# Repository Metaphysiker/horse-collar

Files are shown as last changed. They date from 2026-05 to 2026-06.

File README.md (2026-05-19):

# Horse Collar Monitoring System

Detects horse activity (standing, lying, rolling) and sends alerts for potential colic or distress. Device mounts on a chest belt.

---

## Current Status (2026-05-19)

Hardware ordered from BerryBase, delivery expected 2026-05-19 to 2026-05-21. Nothing built yet.

### Key constraints
- User has **no soldering tools** — all connections must be solderless
- User has a **personal server** for data logging
- Single stable box with some outside space

### Next steps
1. Receive hardware from BerryBase
2. Order weatherproof enclosure from reichelt.de or conrad.ch
3. Order UWB modules from AliExpress (`Makerfabs ESP32 UWB DW1000` x3)
4. Order mini breadboard (~170 pin) to hold boards together
5. Wire up BNO085 to HUZZAH32 via Qwiic cable
6. Set up Arduino IDE and flash firmware
7. Log baseline data for 1 week before building alerts
8. Set up Twilio voice call alerts

---

## Hardware

### Ordered from BerryBase

| Item | Product Nr | Price |
|---|---|---|
| Adafruit BNO085 IMU Breakout | ADA4754 | - |
| Adafruit HUZZAH32 ESP32 Feather (with stacking headers) | ADA3619 | CHF 21.95 |
| LiPo Battery 3.7V 2500mAh JST | LP-785060-J | - |
| 40pin Jumper Female-Female | - | - |
| Soldered easyC/Qwiic to Dupont Female cable | SOL-333314 | - |

### Still needed
- Weatherproof enclosure ~80x65x40mm (IP65/67) — order from reichelt.de or conrad.ch
- UWB modules for height detection (order from AliExpress): `Makerfabs ESP32 UWB DW1000` x3

---

## Wiring

### BNO085 → HUZZAH32
Via Qwiic/STEMMA QT to female jumper wire cable (SOL-333314):

| BNO085 | HUZZAH32 |
|---|---|
| VCC | 3V |
| GND | GND |
| SDA | SDA |
| SCL | SCL |

### Battery → HUZZAH32
JST connector plugs directly into HUZZAH32 JST socket. Charge via Micro-USB into HUZZAH32.

---

## Enclosure

- Target size: ~80x65x40mm
- Must be IP65/67 (weatherproof — horse sweats, rain)
- Fix components inside with double-sided velcro + polyethylene foam padding
- Use small cable tie on Qwiic cable to prevent connector strain
- Use mini breadboard (~170 pin) to hold HUZZAH32 and BNO085 together as one unit

---

## Detection Logic

### Sampling rate
- Read BNO085 every **1 second**
- Send data to server only on **state change** + heartbeat every **5 minutes**

### States
| State | Condition |
|---|---|
| Standing | Stable orientation, pitch/roll ~0° |
| Lying down | Pitch or roll > 60° for more than 10 seconds |
| Moving | Activity detected, upright orientation |
| Rolling (colic risk) | Activity detected + tilted orientation |

### BNO085 data to use
- **Gravity vector** — changes clearly when horse lies down
- **Absolute orientation / rotation vector** — pitch and roll angles
- **Activity classification** — stable, moving etc.
- **Linear acceleration** — sudden movements

### Battery monitoring
Read battery voltage via pin A13 on HUZZAH32:

| Voltage | Charge |
|---|---|
| 4.2V | 100% |
| 3.9V | ~60% |
| 3.7V | ~30% |
| 3.4V | ~5% |

---

## Data Logging (Server)

Log everything first to establish baseline — learn what normal looks like for this specific horse before building alerts.

### Payload (every state change)
```json
{
  "timestamp": "2026-05-19T08:00:00",
  "pitch": 12.3,
  "roll": 2.1,
  "activity": "stable",
  "acceleration": 0.12,
  "battery_voltage": 3.9,
  "battery_percent": 60,
  "state": "standing"
}
```

---

## Alerts (Twilio)

Voice call to mobile when abnormal state detected.

| Destination | Cost |
|---|---|
| Swiss mobile | ~$0.05 per call |
| Swiss landline | ~$0.01 per call |
| Twilio number | $1.15/month |

Trigger alert when:
- Horse rolling for more than 30 seconds (colic risk)
- Horse lying down for unusually long time
- Battery below 20%

---

## Future: UWB Height Detection

3x `Makerfabs ESP32 UWB DW1000` modules (~€60 total from AliExpress):
- Anchor 1: high (stable roof edge) — covers indoor + outdoor
- Anchor 2: low (stable wall, ground level)
- Tag: horse collar

Detects absolute height → confirms lying down independently of IMU orientation.
Combined with BNO085 gives much richer picture (lying + rolling = strong colic indicator).

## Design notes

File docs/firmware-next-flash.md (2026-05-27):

# Planned Firmware Changes (next flash)

## 1. Send quaternion instead of Euler angles

Currently, the firmware converts the BNO085 rotation vector to pitch/roll on-device and discards the quaternion. This causes:
- Gimbal lock (pitch flips to ±127° when roll exceeds 90°)
- Loss of yaw entirely
- Server-side horse roll approximation is inaccurate at high angles

**Change:** Send `qw`, `qx`, `qy`, `qz` raw. Keep pitch/roll alongside for backward compatibility during transition.

```cpp
doc["qw"] = curQw;
doc["qx"] = curQx;
doc["qy"] = curQy;
doc["qz"] = curQz;
```

Server and frontend then compute pitch, roll, yaw, and horse roll from quaternion — no gimbal lock, correct at all angles.

---

## 2. Send Unix timestamp as integer

Currently, `isoFromUnix()` converts `time_t` to an ISO string in firmware. This is unnecessary and error-prone (TZ confusion).

**Change:** Send the raw Unix timestamp directly.

```cpp
// instead of:
obj["timestamp"] = isoFromUnix(r.unixTime);
// send:
obj["timestamp"] = r.unixTime;
```

Server parses with `DateTimeOffset.FromUnixTimeSeconds(v).UtcDateTime`. No conversion, no formatting, always UTC.

---

## 3. Add yaw (compass heading)

`SH2_ROTATION_VECTOR` already uses the magnetometer and is already enabled — yaw costs zero extra sensor reads, just one extra `atan2` computation.

**Change:** Extract yaw from the existing quaternion read.

```cpp
float yaw = atan2(2*(curQw*curQz + curQx*curQy), 1 - 2*(curQy*curQy + curQz*curQz)) * 180.0f / PI;
```

Send as `yaw` field. Useful for detecting which direction the horse is facing and long-term movement patterns.

---

## 4. Re-sync NTP on every WiFi connection

The ESP32 HUZZAH32 has no external 32.768 kHz crystal — it uses an internal 150 kHz RC oscillator which is temperature-sensitive and drifts significantly (~10 min per 36 h observed). NTP is the only source of accurate time.

Currently `timeSynced` is `RTC_DATA_ATTR` — NTP syncs once at hard boot and never again.

Since WiFi is already connected for every batch upload, re-syncing NTP costs almost nothing (one UDP packet). Just remove the `timeSynced` guard so `syncTime()` is called every upload cycle.

**Change:** Remove `RTC_DATA_ATTR bool timeSynced` and always call `syncTime()` when WiFi is up.

---

## 5. Fix timezone offset

`TZ_OFFSET = 3600` (UTC+1, CET) is wrong in summer — Switzerland is CEST (UTC+2 = 7200). Since timestamps use `gmtime()` this is harmless for stored data, but fix for correctness and any local-time logging.

**Change in `config.*.h`:**
```cpp
// Option A: hardcode CEST
#define TZ_OFFSET 7200

// Option B: use POSIX timezone string (handles DST automatically)
configTime(0, 0, NTP_SERVER);
setenv("TZ", "CET-1CEST,M3.5.0,M10.5.0/3", 1);
tzset();
```

Option B is correct year-round.

---

## 6. Additional sensor data (low impact)

These use already-enabled reports or fast additional reads:

| Field | Source | Cost |
|---|---|---|
| `linearAccelX/Y/Z` | `SH2_LINEAR_ACCELERATION` (already enabled) | free — just send components instead of magnitude |
| `gyroX/Y/Z` | `SH2_GYROSCOPE_CALIBRATED` (already enabled) | free — just send components instead of magnitude |
| `gravityX/Y/Z` | `SH2_GRAVITY` | one extra report enable + poll |
| `temperature` | `SH2_TEMPERATURE` | one extra report enable + poll |

Sending raw X/Y/Z components instead of magnitudes gives the server more information to work with (direction of movement, not just intensity).

---

## Summary of JSON payload change

**Current:**
```json
{
  "timestamp": "2026-05-26T17:44:52",
  "pitch": -8.3, "roll": -7.7,
  "acceleration": 0.11, "angularVelocity": 0.03,
  "temperature": 25.0, "state": "Standing", "alertReason": null
}
```

**After:**
```json
{
  "timestamp": 1748283892,
  "qw": 0.997, "qx": -0.042, "qy": -0.031, "qz": 0.012,
  "pitch": -8.3, "roll": -7.7, "yaw": 142.5,
  "acceleration": 0.11, "angularVelocity": 0.03,
  "linearAccelX": 0.08, "linearAccelY": -0.07, "linearAccelZ": 0.03,
  "gyroX": 0.01, "gyroY": -0.02, "gyroZ": 0.01,
  "temperature": 25.0, "state": "Standing", "alertReason": null
}
```

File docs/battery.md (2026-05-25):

# Battery Life Estimates

## Hardware

- **Board:** Adafruit HUZZAH32 (ESP32)
- **Sensor:** BNO085 (~1.1 mA active)
- **Battery:** 2500 mAh LiPo
- **Charger:** built into HUZZAH32, charges at ~200 mA via USB-C

---

## Power consumption

| Mode | Current draw |
|---|---|
| ESP32 deep sleep | ~0.01 mA |
| ESP32 active, WiFi off (sensor read) | ~80 mA |
| ESP32 active, WiFi transmitting | ~180 mA |

---

## Current setup — deep sleep with batch sending

The firmware deep sleeps between readings and only connects to WiFi every `sendEveryN` cycles to upload a batch. WiFi connect + send + disconnect takes ~15 seconds.

**Assumptions:**
- Sensor read per wake: ~500 ms at 80 mA
- WiFi per batch: ~15 s at 180 mA
- `sendEveryN = 60`

| Sleep interval | Upload every | Avg current | Est. battery life (2500 mAh) |
|---|---|---|---|
| 1s | ~60s | ~68 mA | **~37 hours** |
| 2s | ~2 min | ~38 mA | **~66 hours (~2.7 days)** |
| 5s | ~5 min | ~16 mA | **~6.5 days** |
| 10s | ~10 min | ~8 mA | **~13 days** |

---

## Trade-offs

- **1s** — maximum data density, good for active monitoring or data collection sessions
- **2s** — good balance for daily use, ~2.5 days between charges
- **5s** — field deployment, weekly charging
- **10s** — long-term unattended monitoring, charge every ~2 weeks

Alert states always send immediately regardless of interval — battery impact is minimal since alerts are rare.

---

## Notes

- Real-world battery capacity is typically 80–90% of rated value — reduce estimates accordingly.
- WiFi connection time varies by signal strength. Poor signal = longer connect time = faster drain.
- The HUZZAH32 battery percentage reading is approximate (±5–10%).

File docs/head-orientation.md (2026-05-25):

# Head Orientation — How It Works

## The sensor

The BNO085 chip measures orientation relative to gravity. It knows which way is "down" at all times. It reports three values:

- **Pitch (sensor)** — tilt on one axis
- **Roll (sensor)** — tilt on the other axis
- **Yaw (sensor)** — rotation around the vertical axis (like a compass heading)

## The problem: we don't know how the chip sits in the casing

The chip is glued inside a plastic casing in some unknown rotation. This means we don't know which sensor axis maps to which head movement. What the sensor calls "pitch" might actually be the head tilting sideways, or forward, depending on how the chip is mounted.

## What the horse's head can do

- **Pitch (horse)** — nose pointing up or down (like nodding yes)
- **Roll (horse)** — head tilting sideways, ear toward shoulder (like tilting an airplane wing)
- **Yaw (horse)** — head turning left or right (like saying no) — this is compass direction

## What we actually care about for lying down detection

When a horse lies down on its side, the head **rolls (horse)** heavily to one side — the ear goes toward the ground. This is a large, sustained change in orientation.

The problem: we don't know if roll (horse) shows up as pitch (sensor), roll (sensor), or a mix of both, because we don't know the chip orientation.

## How to figure it out

Look at the sensor data during a confirmed lying-down period. One or both of pitch (sensor) / roll (sensor) will show a large, sustained value that is clearly different from when the horse is standing. That's your roll (horse) signal.

## Tilt — a shortcut that avoids the chip orientation problem

Tilt is calculated as:

```
tilt = sqrt(pitch² + roll²)
```

This is Pythagoras applied to angles. It measures the total deviation from level, regardless of which direction. It doesn't matter how the chip is rotated in the casing — tilt will always be large when the head is far from level.

- Horse standing normally: tilt ≈ 17–28° (head slightly forward and down is normal)
- Horse lying on its side: tilt expected to be much larger (60–90°+)

Tilt doesn't tell you which direction the head tilted, just how far. But for detecting lying down, that's enough.

## What the overnight data will tell us

By leaving the collar on overnight and looking at the data:

1. **If the horse lies down** — we'll see a long period of low acceleration (still) with high tilt. We can measure the exact tilt range for lying down and use it as a threshold.

2. **If the horse never lies down** — we still have a solid baseline for "normal upright active head." Any sustained reading outside that range is unusual and worth flagging.

## Bonus: compass direction

Yaw (sensor) tells you which direction the horse's nose is pointing — north, east, west, etc. Not useful for health monitoring, but interesting.

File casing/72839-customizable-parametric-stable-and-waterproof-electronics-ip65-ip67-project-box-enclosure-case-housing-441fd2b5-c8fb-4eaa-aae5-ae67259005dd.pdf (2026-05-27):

## Customizable parametric stable

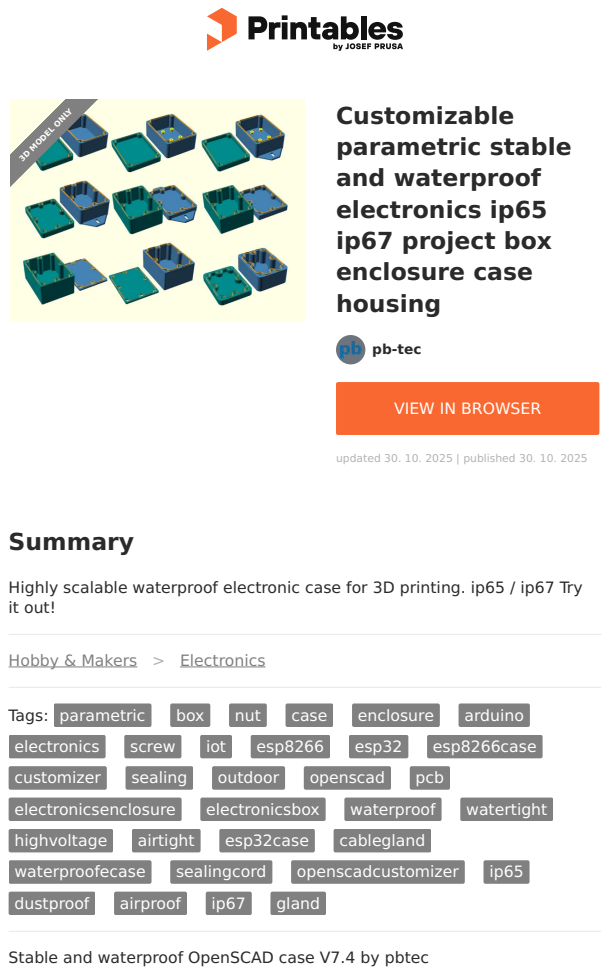
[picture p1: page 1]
Summary; Tags:; parametric; box; nut; case; enclosure; arduino; electronics; screw; iot; esp8266; esp32; esp8266case; customizer; sealing; outdoor; openscad; pcb; electronicsenclosure; electronicsbox; waterproof; watertight; highvoltage; airtight; esp32case; cablegland; waterproofecase; sealingcord; openscadcustomizer; dustproof; airproof; gland; pb-tec; and waterproof electronics ip65 ip67 project box enclosure case housing; updated 30. 10. 2025 | published 30. 10. 2025; 3D MODEL ONLY

VIEW IN BROWSER (https://printables.com/model/72839-customizable-parametric-stable-and-waterproof-elec)

Highly scalable waterproof electronic case for 3D printing. ip65 / ip67 Try
it out!

Hobby & Makers (https://printables.com/model?categoryId=48) > Electronics (https://printables.com/model?categoryId=52)

Stable and waterproof OpenSCAD case V7.4 by pbtec

See here a wonderful comment from a user:
“This is INSANE! You sir deserve deserve the biggest applaud out there. This is a box to rule them all! ... I have to admit I first didn't understand what you meant with SCAD possibilities, and resized it on my own by cutting xD then I checked out SCAD version and my jaw simply dropped to the ground! ... This is a GREAT project!”

Highly scalable electronic case for 3D printing. Try it out!
You’ll need to download the free, opensource OpenSCAD software from https://openscad.org/ and install it. Once installed, open the ".scad" file in Openscad. Activate Customizer under View/Customizer and have fun experimenting!

Fixed version 7.4
It seems that special characters in the code have again led to the code not working properly for some. I apologize for this. I have now created a new version 7.4 where this is fixed. I would be very interested to know if everything works as expected for you now. Thanks for your feedback in the comments

Enhancements in Version 7.2:

Hot melt copper nut support
Screw hole options: Can be configured to pass through the entire case, with the option to position the nut at the bottom of the case Flexible mounting options: 1 to 3 holes on all sides for cable glands or switches
Improved PCB support: Now compatible with up to 3 different PCBs holders instead of just one
Base bottom mounting holes added (not recommended if the housing should be highly waterproof)
Gasket can now be printed (TPU).
Expanded screw support: In addition to countersunk screws, round, flat, and hex head screws are now supported

I would love to hear whether you like the new version!

No support needed to print

You don't know Openscad? No problem. Customize the case in Openscad and then export the stl file from Openscad (F6 then F7). Then Import the stl file into your best known 3d program to make holes for example. You can also make the holes afterwards with the drilling machine ;-)

Additional Screws (M2,M2.5,M3,M4 or M5), the matching nuts (hex or square) needed.
If you want to protect your electronics from humidity also “silicone sealing cord” is needed. Available at AliExpress or ebay.

•
•

•

•

•

•
•

For waterproof cases you can use silicone sealing cord with diameters from 1 to 3mm
To use also without sealing cord. The groove and ridge gives the housing a high stability and tightness.
Use of regular nuts or square nuts
Define outer vertical radius of corners
Echo output in console shows inner and outer size and more
Echo output shows the needed length of the screws
Use screws from m2 up to m5
Default are 4 screws at each corner. For large cases add addtional ones in the middle of both x and y sides if needed
Use several predefined wall mount holder, some with multiple mounting holes (up to 3)

Important!
If you use standard or square nuts, you need to pause the printer a certain level to insert the nuts
If you need a stable and waterproof case please print with 100% infill I'm aware that sometimes, when using too big or too small parameters, there are some rendering issues. To prevent such issues change only one parameter at once and check the result.

I never tested the water proofness of this case. For more information see https://blog.prusaprinters.org/watertight-3d-printing-part-2_53638/

pbtec / pb-tec.ch
https://www.instagram.com/pbtecch/

For Projects with ESP32, ESP8266, Arduino, Raspberry, Sonoff, Shelly, IoBroker, IoT. In- and outdoor :-)

Let me see your prints, and remakes and pls don't forget to like this print

use https://paypal.me/pbtec if you want to spend me a cold beer. Thanks in advance :-)

If you want to support my project, please use the links below to start your shopping. No additional charges for you, but I get a commission of your purchases

Brass hot melting insert nuts (starter) sets: https://s.click.aliexpress.com/e/_DezuAlHhttps://s.click.aliexpress.com/e/_DeWsPMp

Or individual sizes:
https://s.click.aliexpress.com/e/_DkaQObjhttps://s.click.aliexpress.com/e/_DCrO22p

## Model files

I also recommend using special hot iron to insert the nuts in the right angle:
https://s.click.aliexpress.com/e/_DcHd8Ep

round silicone sealing cord foam white
Aliexpress: https://s.click.aliexpress.com/e/_AdVXC6
Ebay: https://www.ebay.com/itm/184394411044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 (https://www.ebay.com/itm/184394411044?siteid=0&campid=5338823684&customid=&toolid=10001)

round silicone sealing cord foam black
Aliexpress: https://s.click.aliexpress.com/e/_A32aUQ
Ebay: https://www.ebay.com/itm/353309685702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 (https://www.ebay.com/itm/353309685702?siteid=0&campid=5338823684&customid=&toolid=10001)

round silicone sealing solid cord white
Aliexpress: https://s.click.aliexpress.com/e/_A07nM2
Ebay: https://www.ebay.com/itm/133527877200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 (https://www.ebay.com/itm/133527877200?siteid=0&campid=5338823684&customid=&toolid=10001)

Some tags to better find this project:
Electrical Junction, Distribution box, Connection box, Cable Branch box,
Electronic, Housing, ip67, DIY, Project Box, Instrument Case, Wiring socket
box, Sealed, Cable gland, Shell, weatherproof, outdoor, airtight, watertight, dustproof, electronics, pcb, airproof, enclosure, parametric

sample2-ultimatewaterproofcase_v6.stl

sample1-ultimatewaterproofcase_v6.stl

ultimatewaterproofcase_v61.scad

ultimatewaterproofcase_v74.scad

## License

This work is licensed under a
Creative Commons (4.0 International License)

Attribution—Noncommercial—Share Alike (http://creativecommons.org/licenses/by-nc-sa/4.0/)

✖ | Sharing without ATTRIBUTION
✔ | Remix Culture allowed
✖ | Commercial Use
✖ | Free Cultural Works
✖ | Meets Open Definition

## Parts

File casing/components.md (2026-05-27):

# Component Dimensions

## LiPo Battery
- **Part:** PKCell LP-785060-J
- **EAN:** 4251266702207
- **Size:** 7.8 × 50 × 60 mm
- **Voltage:** 3.7V DC (single cell)
- **Weight:** 54g gross

## Adafruit HUZZAH32 (ESP32 Feather)
- **Part:** Adafruit #3619
- **EAN:** 4060137061714
- **Size:** 22.9 × 57.1 mm (verify height with components)
- **Weight:** 10g gross
- **Origin:** USA
- **MCU:** ESP32 dual core 240 MHz Tensilica LX6
- **RAM:** 520 KB SRAM
- **Flash:** 4 MB (on WROOM32 module)
- **WiFi:** 802.11b/g/n, integrated PCB antenna
- **Bluetooth:** Classic + BLE
- **RTC:** ESP32 supports external 32 kHz crystal, but HUZZAH32 does not populate it — uses internal RC oscillator (~150 kHz, drifts significantly)
- Includes USB interface, LiPo JST connector, reset button
- LiPo battery and USB cable not included

## BNO085 IMU Breakout
- **Part:** Adafruit #4754
- **EAN:** 4060137066818
- **Size:** 25.6 × 22.7 × 4.6 mm
- **Weight:** 2.5g
- **Origin:** USA
- Connected via I2C (4 wires)

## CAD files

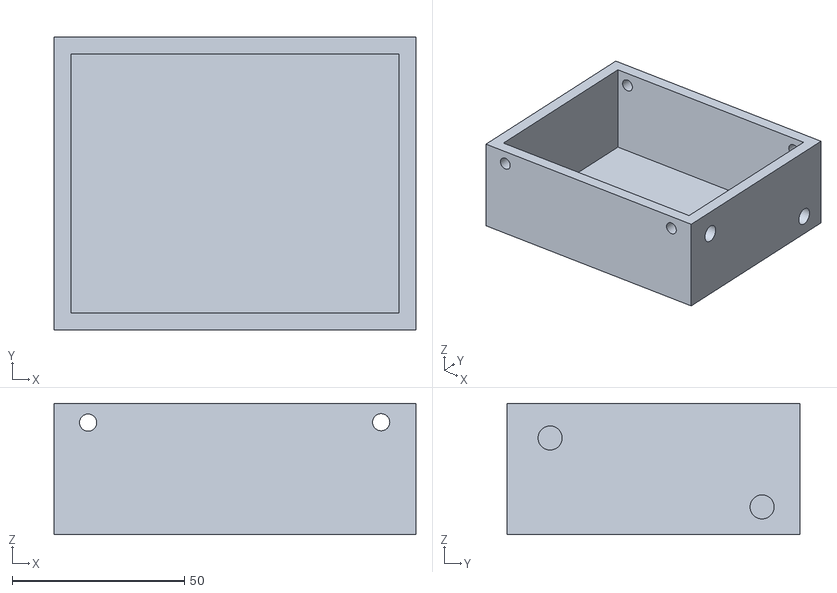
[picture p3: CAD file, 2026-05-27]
casing/MainBody.stl
105.0 x 85.0 x 38.0

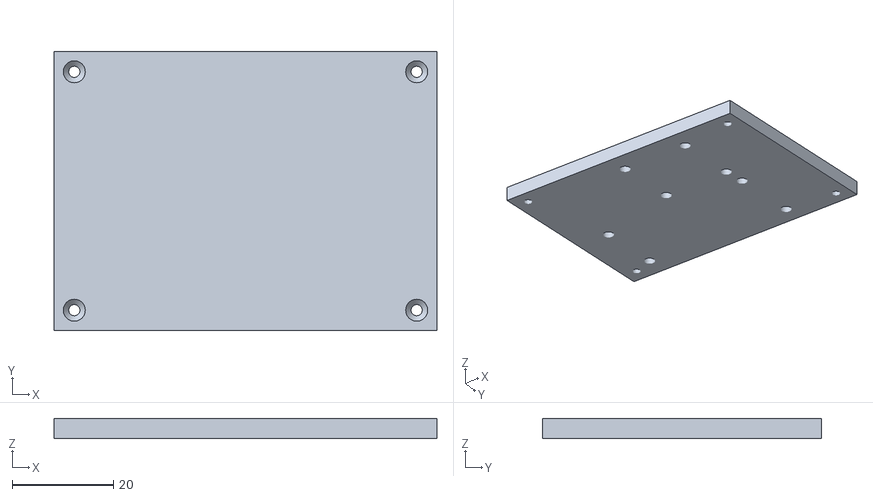
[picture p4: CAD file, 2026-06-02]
casing/20260519-horse-collar-with-heat-inserts/horse-collar-with-heat-inserts-lid.stl
75.5 x 55.0 x 4.00

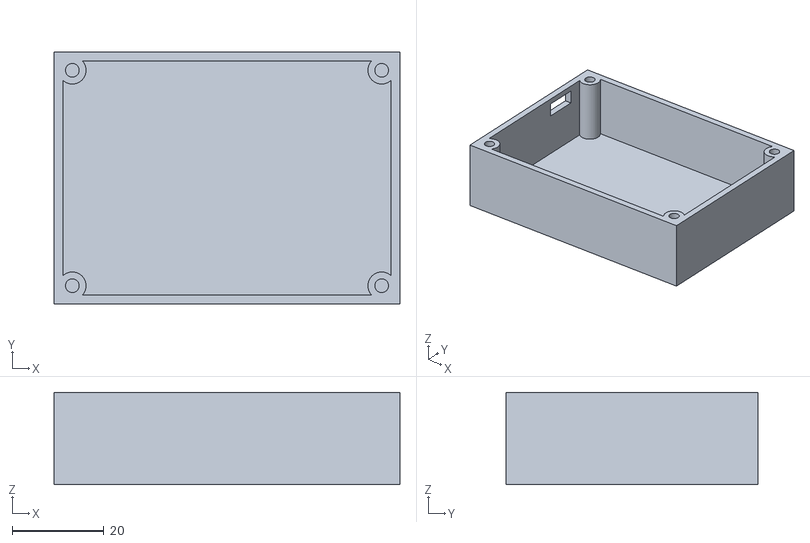
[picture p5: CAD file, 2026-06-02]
casing/20260519-horse-collar-with-heat-inserts/horse-collar-with-heat-inserts-box.stl
75.5 x 55.0 x 20.1

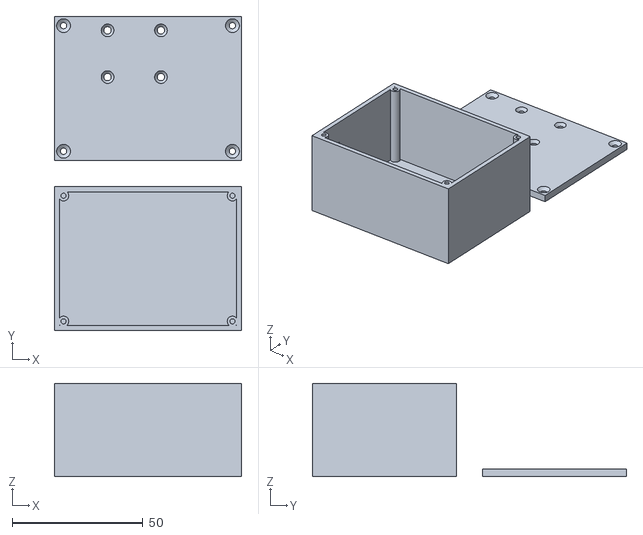
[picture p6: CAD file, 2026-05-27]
casing/sandro-box.stl
71.5 x 120.0 x 35.7

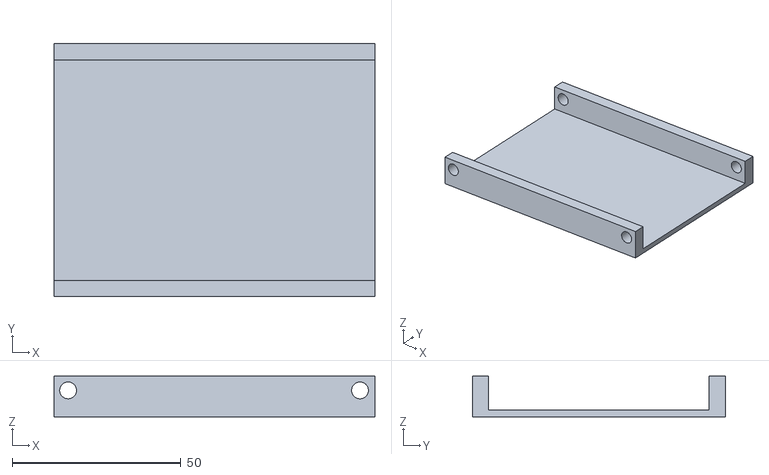
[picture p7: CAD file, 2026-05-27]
casing/Lid.stl
95.0 x 75.0 x 12.0

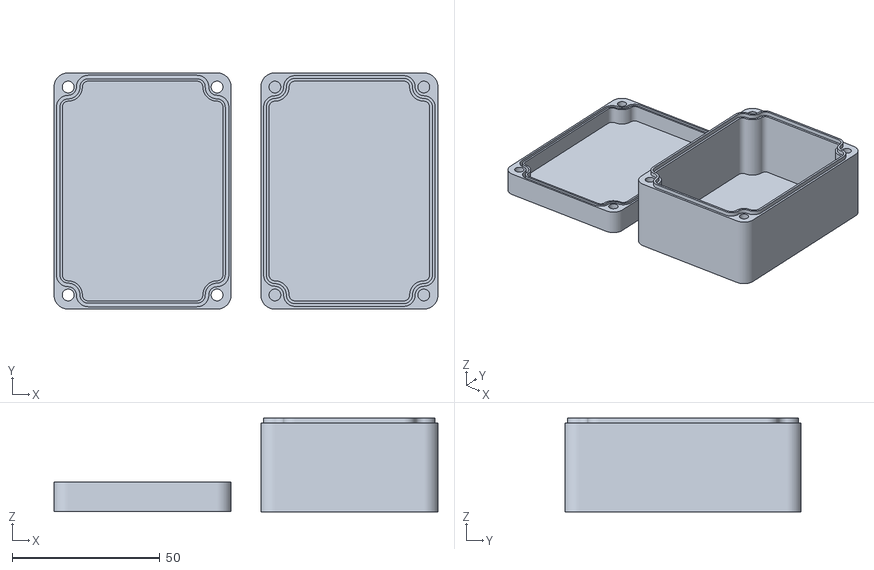
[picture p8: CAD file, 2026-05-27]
casing/Sample1-UltimateWaterproofCase_V6.stl
130.0 x 80.0 x 31.7

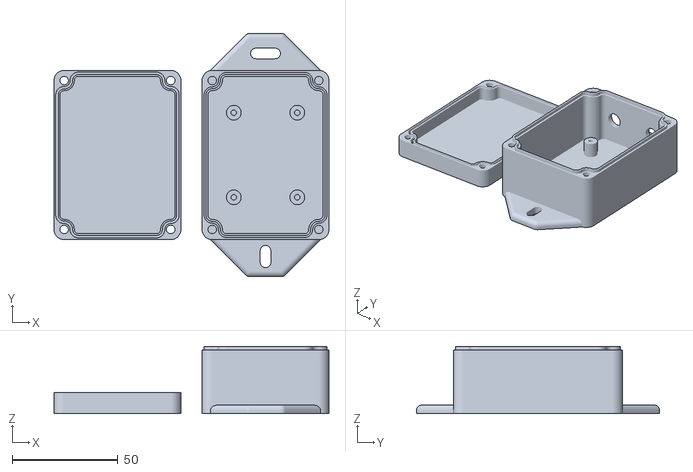
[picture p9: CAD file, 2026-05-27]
casing/sample2-ultimatewaterproofcase_v6.stl
130.0 x 115.0 x 31.7

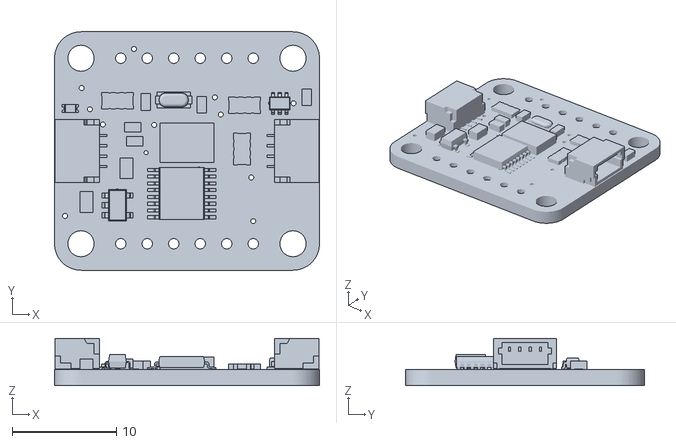
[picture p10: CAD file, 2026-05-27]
casing/4754 BNO085 STEMMA QT.stl
25.4 x 22.9 x 4.53

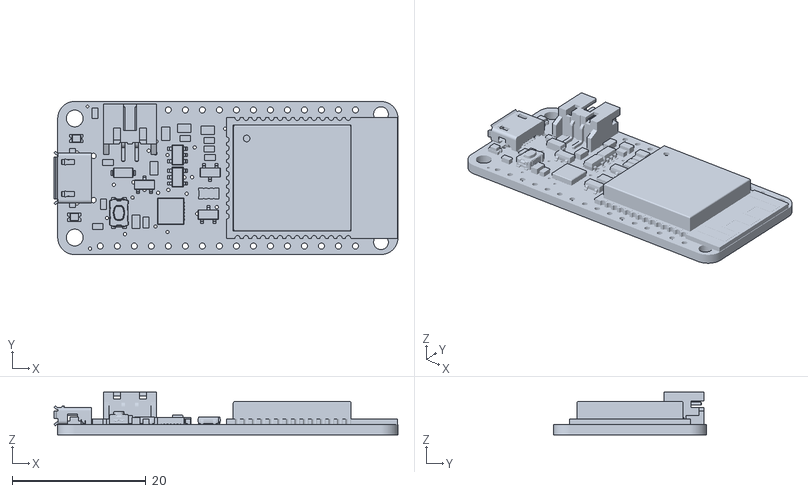
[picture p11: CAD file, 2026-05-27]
casing/3405 Adafruit HUZZAH32 ESP32 Feather.stl
51.4 x 22.9 x 6.37

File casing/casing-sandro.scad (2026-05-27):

module lid(){

    LID_SKIN = 2.5;   // top plate thickness (critical rigidity parameter)

    difference(){

        // ── Solid lid blank (structural cap) ───────────────
        rbox(OUT_L, OUT_W, LID_H);

        // ── Main internal clearance (BUT not full height) ──
        // Leaves a solid top skin
        translate([wall, wall, LID_SKIN])
            cube([
                IN_L,
                IN_W,
                LID_H - LID_SKIN + 1
            ]);

        // ── HUZZAH32 pocket (only where needed) ────────────
        translate([wall + HUZ_OFF_L,
                   wall + HUZ_OFF_W,
                   LID_SKIN])
            cube([
                HUZ_L + tol,
                HUZ_CAV_H,
                HUZ_W + tol
            ]);

        // ── BNO085 pocket ──────────────────────────────────
        translate([wall + BNO_OFF_L,
                   wall + BNO_OFF_W,
                   LID_SKIN])
            cube([
                BNO_L + tol,
                BNO_W + tol,
                BNO_H + tol
            ]);

        // ── Alignment post holes ───────────────────────────
        for (x=[10, OUT_L-10], y=[10, OUT_W-10])
            translate([x,y,-1])
                cylinder(d=post_fit, h=LID_SKIN + 20);

        // ── Screw clearance holes ──────────────────────────
        for (x=[10, OUT_L-10], y=[10, OUT_W-10])
            translate([x,y,-1])
                cylinder(d=screw_d, h=LID_H + 2);

        // ── USB-C cutout ───────────────────────────────────
        translate([OUT_L - wall - 0.1,
                   wall + HUZ_OFF_W + 8,
                   LID_SKIN + 2])
            cube([wall + 0.2, 10, 5]);

        // ── LED window ──────────────────────────────────────
        translate([wall + HUZ_OFF_L + 5,
                   OUT_W - wall - 0.1,
                   LID_SKIN + 2])
            cube([6, wall + 0.2, 3]);
    }
}

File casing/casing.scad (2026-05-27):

// ── Horse Collar Sensor Casing ───────────────────────────────────────
//
// Components:
//   Battery  PKCell LP-785060-J   7.8 × 50 × 60 mm  (lying flat, bottom layer)
//   HUZZAH32 Adafruit #3619      22.9 × 57.1 mm PCB (middle layer, centred)
//   BNO085   Adafruit #4754      25.6 × 22.7 × 4.6 mm (top layer, one end)
//
// Two-part print: bottom shell (battery) + lid (HUZZAH32 + BNO085)
// Joined by snap rim: rim on bottom shell slots into groove in lid.

// ── Tuneables ────────────────────────────────────────────────────────
show_shell      = true;   // show the printed shells
show_components = true;   // show battery / HUZZAH32 / BNO085

wall  = 2.0;   // shell wall / floor / ceiling thickness
tol   = 0.5;   // clearance added to each component cavity
cr    = 3.0;   // outer corner radius
$fn   = 40;

// Corner screws joining lid to bottom shell (M2.5, 4 corners)
screw_clr_d   = 2.7;   // M2.5 clearance hole through lid
screw_head_d  = 5.0;   // M2.5 pan head recess diameter
screw_head_h  = 1.8;   // pan head recess depth
screw_pilot_d = 2.0;   // M2.5 pilot hole in bottom shell (self-tapping)
screw_pilot_h = 8.0;   // pilot hole depth

// HUZZAH32 PCB locating pegs (press-fit into Adafruit Feather mounting holes)
pcb_peg_d      = 2.0;   // peg diameter — tight in 2.2 mm Feather holes; sand if needed
pcb_peg_h      = 3.5;   // peg height
HUZ_HOLE_IN_L  = 3.2;   // hole inset from short edge  (Adafruit Feather standard)
HUZ_HOLE_IN_W  = 1.7;   // hole inset from long edge

// BNO085 boss posts (M2.0 self-tapping screws inserted from inside case, up through PCB hole)
bno_boss_d     = 4.0;   // outer boss diameter
bno_screw_d    = 1.6;   // pilot hole diameter for M2 self-tapping
bno_pilot_dep  = 8.0;   // pilot hole depth into boss

// ── Component dimensions ─────────────────────────────────────────────
BAT_L = 60.0;   BAT_W = 50.0;   BAT_H = 7.8;

HUZ_L = 57.1;   HUZ_W = 22.9;
HUZ_PCB_H  = 1.6;    // PCB thickness
HUZ_COMP_H = 9.0;    // tallest SMD component above PCB (USB-C port)
HUZ_PIN_H  = 12.0;   // male pin tail below PCB — measured from female jumper cable (~12 mm)
HUZ_FEM_H  = 12.0;   // female Dupont socket height above PCB — measured jumper cable
HDR_W      = 2.54;   // header strip width (one row of 2.54mm pitch)
HUZ_H = HUZ_PCB_H + max(HUZ_COMP_H, HUZ_PIN_H);

BNO_L = 25.4;   BNO_W = 22.86;  BNO_H = 4.53;  // measured from STL bounding box

// ── Layout ───────────────────────────────────────────────────────────
// HUZZAH32 and BNO085 sit side-by-side in the width direction, centred together.
// Combined width: 22.9 + 2mm gap + 22.86 = 47.76mm — fits in 50mm inner width.

IN_L = BAT_L;                          // inner length = 60 mm
IN_W = BAT_W;                          // inner width  = 50 mm

OUT_L = IN_L + 2 * wall;
OUT_W = IN_W + 2 * wall;

BOT_H = wall + BAT_H + wall;           // bottom shell total height
LID_H = wall + HUZ_W + wall;           // lid total height — HUZZAH32 stands upright, height = HUZ_W

BNO_GAP   = 2.0;
BOARDS_W  = HUZ_W + BNO_GAP + BNO_W;

HUZ_OFF_L = (IN_L - HUZ_L) / 2;
HUZ_OFF_W = (IN_W - BOARDS_W) / 2;

BNO_OFF_L = (IN_L - BNO_L) / 2;
BNO_OFF_W = IN_W - BNO_W;

// HUZZAH32 mounting hole positions relative to PCB corner
huz_holes = [
  [HUZ_HOLE_IN_L,         HUZ_HOLE_IN_W        ],
  [HUZ_L - HUZ_HOLE_IN_L, HUZ_HOLE_IN_W        ],
  [HUZ_HOLE_IN_L,         HUZ_W - HUZ_HOLE_IN_W],
  [HUZ_L - HUZ_HOLE_IN_L, HUZ_W - HUZ_HOLE_IN_W],
];

// BNO085 mounting hole positions relative to board corner (from Adafruit Eagle PCB file)
bno_holes = [
  [ 2.54,  2.54],
  [22.86,  2.54],
  [ 2.54, 20.32],
  [22.86, 20.32],
];

// USB-C cutout
USB_W = 9.5;
USB_H = 4.0;
usb_y = wall + HUZ_OFF_W + HUZ_W / 2 - USB_W / 2;
usb_z = wall + HUZ_PCB_H;

// ── Component models ─────────────────────────────────────────────────
module huzzah32() {
    // STL (offset corrected — model origin is at x=−0.56)
    color("ForestGreen", 0.8) translate([0.56, 0, 0])
        import("3405 Adafruit HUZZAH32 ESP32 Feather.stl");
    // PCB slab
    color("ForestGreen", 0.4) cube([HUZ_L, HUZ_W, HUZ_PCB_H]);
    // Female headers — both long sides, above PCB
    color("Gold", 0.5) translate([0, 0, HUZ_PCB_H])
        cube([HUZ_L, HDR_W, HUZ_FEM_H]);
    color("Gold", 0.5) translate([0, HUZ_W - HDR_W, HUZ_PCB_H])
        cube([HUZ_L, HDR_W, HUZ_FEM_H]);
    // Male pins — both long sides, below PCB (sticking out from belly)
    color("CornflowerBlue", 0.8) translate([0, 0, -HUZ_PIN_H])
        cube([HUZ_L, HDR_W, HUZ_PIN_H]);
    color("CornflowerBlue", 0.8) translate([0, HUZ_W - HDR_W, -HUZ_PIN_H])
        cube([HUZ_L, HDR_W, HUZ_PIN_H]);
}

// ── Primitives ───────────────────────────────────────────────────────
module rbox(l, w, h) {
    hull()
        for (x = [cr, l - cr], y = [cr, w - cr])
            translate([x, y, 0]) cylinder(r = cr, h = h);
}

// Rectangular frame (solid outer minus hollow inner)
module rim_frame(l, w, h, t) {
    difference() {
        cube([l, w, h]);
        translate([t, t, -0.1])
            cube([l - 2*t, w - 2*t, h + 0.2]);
    }
}

// ── Bottom shell ─────────────────────────────────────────────────────
module bottom() {
    difference() {
        rbox(OUT_L, OUT_W, BOT_H);

        // Battery cavity (open top)
        translate([wall, wall, wall])
            cube([BAT_L + tol, BAT_W + tol, BOT_H]);

        // Groove clearance so rim doesn't hit the lid groove shoulder
        // (nothing to subtract here — open top handles it)
    }

    // Snap rim — rises from battery tray walls, slots into lid groove
    translate([wall, wall, BOT_H])
        rim_frame(IN_L, IN_W, snap_rim_h, snap_rim_t);
}

// ── Lid ──────────────────────────────────────────────────────────────
module lid() {
    difference() {
        union() {
            rbox(OUT_L, OUT_W, LID_H);

            // HUZZAH32 PCB locating pegs — hang from lid ceiling
            for (h = huz_holes)
                translate([wall + HUZ_OFF_L + h[0], wall + HUZ_OFF_W + h[1], LID_H - wall - pcb_peg_h])
                    cylinder(d = pcb_peg_d, h = pcb_peg_h);

            // BNO085 boss posts — hang from ceiling; PCB rests against boss tip, screw from inside
            for (h = bno_holes)
                translate([wall + BNO_OFF_L + h[0], wall + BNO_OFF_W + h[1], BNO_H + tol])
                    cylinder(d = bno_boss_d, h = LID_H - wall - BNO_H - tol);
        }

        // HUZZAH32 cavity (open bottom) — upright: depth=HUZ_W, Y-width=full header stack
        translate([wall + HUZ_OFF_L, wall + HUZ_OFF_W, -1])
            cube([HUZ_L + tol, HUZ_PIN_H + HUZ_PCB_H + HUZ_FEM_H + tol, HUZ_W + tol + 1]);

        // BNO085 cavity (open bottom)
        translate([wall + BNO_OFF_L, wall + BNO_OFF_W, -1])
            cube([BNO_L + tol, BNO_W + tol, BNO_H + tol + 1]);

        // Snap groove — frame-shaped recess at open bottom, accepts bottom shell rim
        translate([wall - snap_tol, wall - snap_tol, -1])
            rim_frame(
                IN_L + 2*snap_tol,
                IN_W + 2*snap_tol,
                snap_rim_h + 1,
                snap_rim_t + snap_tol
            );

        // USB-C cutout on right short face
        translate([OUT_L - wall - 0.1, usb_y, usb_z])
            cube([wall + 0.2, USB_W, USB_H]);

        // LED window on long face
        translate([wall + HUZ_OFF_L + 3, OUT_W - wall - 0.1, usb_z])
            cube([5, wall + 0.2, 3]);

        // BNO085 pilot holes — blind, from boss bottom upward (M2 screws from inside case)
        for (h = bno_holes)
            translate([wall + BNO_OFF_L + h[0], wall + BNO_OFF_W + h[1], BNO_H + tol - 0.1])
                cylinder(d = bno_screw_d, h = bno_pilot_dep + 0.1);
    }
}

// ── Dimensions ───────────────────────────────────────────────────────
echo(str("Outer footprint: ", OUT_L, " × ", OUT_W, " mm"));
echo(str("Bottom shell height: ", BOT_H, " mm"));
echo(str("Lid height:          ", LID_H, " mm"));
echo(str("Total assembled:     ", OUT_L, " × ", OUT_W, " × ", BOT_H + LID_H, " mm"));

// ── Render ───────────────────────────────────────────────────────────
if (show_shell) {
    % bottom();
    % translate([0, 0, BOT_H + 5]) lid();
}

if (show_components) {
    color("OrangeRed",    0.5) translate([wall, wall, wall])
        cube([BAT_L, BAT_W, BAT_H]);
    translate([wall + HUZ_OFF_L, wall + HUZ_OFF_W + HUZ_PCB_H + HUZ_FEM_H, wall + BAT_H + 1])
        rotate([90, 0, 0]) huzzah32();
    color("#1a1a1a") translate([wall + BNO_OFF_L, wall + BNO_OFF_W, BOT_H + 5 + wall + BNO_H])
        mirror([0, 0, 1])
            import("4754 BNO085 STEMMA QT.stl");
    // BNO085 boss posts — shown in component view for layout checking
    color("SteelBlue", 0.8)
        for (h = bno_holes)
            translate([wall + BNO_OFF_L + h[0], wall + BNO_OFF_W + h[1], BOT_H + 5 + wall + BNO_H + tol])
                cylinder(d = bno_boss_d, h = LID_H - wall - BNO_H - tol);
}

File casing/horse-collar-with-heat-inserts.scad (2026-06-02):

// ── Horse Collar Sensor Casing (heat-set insert version) ───────────────
// Components: LiPo Battery + HUZZAH32 (no headers) + BNO085
// Two-part print: box (battery) + flat lid (boards screwed in), joined by 4 corner M2 screws
// HUZZAH32 and BNO085 screwed face-down to lid via M2 heat-set inserts in boss posts

// ── Tuneables ──────────────────────────────────────────────────────────
// "box" = export box STL  |  "lid" = export lid STL  |  "preview" = both side by side  |  "assembled" = alignment check
part = "lid";
lid_assembled = (part == "assembled");
wall        = 2.0;   // wall and floor thickness
lid_depth   = 4.0;   // lid thickness — 4 mm minimum for M2 heat-set inserts
gap         = 3;   // clearance between battery top and board components
boards_gap  = 2.0;   // gap between HUZZAH32 and BNO085 in width direction
$fn         = 40;

// ── Component dimensions ───────────────────────────────────────────────
bat_length = 60.5;   bat_width = 50.0;   bat_depth = 7.8;

huz_length     = 51.0;    // official Adafruit + STL confirmed
huz_width      = 22.86;   // STL measured
huz_pcb_depth  = 1.6;     // PCB thickness
huz_comp_depth = 5.7;     // official total 7.3mm - PCB 1.6mm
huz_depth      = huz_pcb_depth + huz_comp_depth;

bno_length = 25.4;   bno_width = 22.86;   bno_depth = 4.53;

// USB-C cutout
usb_w = 9.5;
usb_h = 4.0;

// ── Mounting holes ─────────────────────────────────────────────────────
// BNO085 (from Adafruit Eagle PCB — 2.54 mm inset from each edge)
bno_holes  = [[2.54, 2.54], [22.86, 2.54], [2.54, 20.32], [22.86, 20.32]];
bno_hole_d = 2.2;   // M2 clearance

// HUZZAH32 mounting holes
// Eagle PCB positions + 0.56 mm STL X origin offset (STL starts at x=-0.56, corrected in huzzah32())
huz_stl_x = 0.56;
huz_holes = [
    [2.54  + huz_stl_x,  2.54],
    [48.26 + huz_stl_x,  1.84],
    [2.54  + huz_stl_x, 20.32],
    [48.26 + huz_stl_x, 20.96],
];
huz_hole_d = 2.2;   // M2 clearance

// ── Corner screw posts (M2) ───────────────────────────────────────────
post_od     = 6.0;   // outer diameter — sized for M2 heat-set insert
csink_d     = 4.5;
csink_depth = 1.4;
screw_clr_d = 2.2;   // M2 clearance through lid

// ── Corner heat-set inserts (M2) ──────────────────────────────────────
// M2 insert: 3.0 mm hole, 3.0 mm long — same spec as board inserts
// Use M2 × 8 mm screws
corner_ins_depth  = 3.0;
corner_ins_hole_d = 3.0;

// ── Board heat-set inserts (M2) ────────────────────────────────────────
// M2 insert: 3.2 mm OD, 3.0 mm long — boss hangs from lid interior
ins_depth  = 3.0;   // M2 insert length
ins_hole_d = 3.0;   // hole diameter (slightly under insert OD for press fit)

// ── Box dimensions ─────────────────────────────────────────────────────
bat_clear_x   = 0.5;   // clearance between battery and post inner edge (x, each side)
bat_clear_x_y = 0.5;   // clearance between battery and wall (y, each side)
// Length: battery + two end zones derived from post position (wall + post_od - 1 = screw_off + post_od/2)
box_length = bat_length + (wall + post_od - 1 + bat_clear_x) * 2;
box_width  = bat_width  + wall * 2 + bat_clear_x_y * 2;
// Depth: floor + battery + gap + boards hanging from lid
box_depth  = wall + bat_depth + gap + huz_depth;

inner_length = box_length - 2 * wall;
inner_width  = box_width  - 2 * wall;
inner_depth  = box_depth  - wall;

post_depth = box_depth - wall;
screw_off  = wall + post_od / 2 - 1;  // 1 mm into wall — insert hole still clears outer face

// ── Board layout (assembly / box coordinates) ──────────────────────────
// HUZZAH32: USB-C end flush with right wall; both boards centred in width
boards_total_width = huz_width + boards_gap + bno_width;
boards_start_y = wall + (inner_width - boards_total_width) / 2;

huz_off_x = 7;    // USB-C channel 9 mm deep
bno_off_y = boards_start_y;                                // BNO at low Y side
huz_off_y = boards_start_y + bno_width + boards_gap;       // HUZZAH at high Y side
bno_off_x = huz_off_x + huz_length - bno_length;           // BNO right-aligned under HUZZAH, away from JST port

// USB-C cutout position on right wall
usb_y = huz_off_y + huz_width / 2 - usb_w / 2;
usb_z = box_depth - huz_pcb_depth - usb_h;

// ── Modules ────────────────────────────────────────────────────────────

module box_body() {
    difference() {
        cube([box_length, box_width, box_depth]);
        // Hollow inside
        translate([wall, wall, wall])
            cube([inner_length, inner_width, inner_depth + 0.1]);
        // USB-C channel: cuts through left wall and into interior to reach port
        translate([-0.1, usb_y, usb_z])
            cube([huz_off_x + wall + 0.2, usb_w, usb_h]);
    }
}

module corner_post(x, y) {
    difference() {
        translate([x, y, wall])
            cylinder(h = post_depth, d = post_od);
        translate([x, y, wall + post_depth - corner_ins_depth])
            cylinder(h = corner_ins_depth + 0.1, d = corner_ins_hole_d);
    }
}

module corner_screw_hole() {
    cylinder(h = lid_depth + 0.2, d = screw_clr_d);
    cylinder(h = csink_depth, d1 = csink_d, d2 = screw_clr_d);
}

module lid() {
    difference() {
        cube([box_length, box_width, lid_depth]);
        // Corner screws
        translate([screw_off,              screw_off,            -0.1]) corner_screw_hole();
        translate([box_length - screw_off, screw_off,            -0.1]) corner_screw_hole();
        translate([screw_off,              box_width - screw_off,-0.1]) corner_screw_hole();
        translate([box_length - screw_off, box_width - screw_off,-0.1]) corner_screw_hole();
        // Heat-set insert holes — blind holes from interior face (z=lid_depth) going inward
        // PCB sits against interior face; screw enters from below through PCB hole into insert
        for (h = huz_holes)
            translate([huz_off_x + h[0], huz_off_y + h[1], lid_depth - ins_depth])
                cylinder(h = ins_depth + 0.1, d = ins_hole_d, $fn = 32);
        for (h = bno_holes)
            translate([bno_off_x + h[0], bno_off_y + h[1], lid_depth - ins_depth])
                cylinder(h = ins_depth + 0.1, d = ins_hole_d, $fn = 32);
    }
}

module huzzah32() {
    // STL origin is at x=-0.56 — shift so PCB left edge = x=0
    color("ForestGreen", 0.15) translate([0.56, 0, 0])
        import("3405 Adafruit HUZZAH32 ESP32 Feather.stl");
}

// Both boards face down from lid: PCB at z=box_depth, components hang into box
module place_huzzah() {
    translate([huz_off_x, huz_off_y + huz_width, box_depth])
        rotate([180, 0, 0])
            huzzah32();
}

module place_bno() {
    translate([bno_off_x, bno_off_y + bno_width, box_depth])
        rotate([180, 0, 0])
            import("4754 BNO085 STEMMA QT.stl");
}

module place_battery() {
    color("SkyBlue")
        translate([wall + post_od - 1 + bat_clear_x, wall + bat_clear_x_y, wall])
            cube([bat_length, bat_width, bat_depth]);
}

// ── Assembly ───────────────────────────────────────────────────────────
module box_assembly() {
    box_body();
    corner_post(screw_off,              screw_off);
    corner_post(box_length - screw_off, screw_off);
    corner_post(screw_off,              box_width - screw_off);
    corner_post(box_length - screw_off, box_width - screw_off);
}

module lid_print() {
    translate([0, 0, lid_depth])
        mirror([0, 0, 1])
            lid();
}

if (part == "box") {
    box_assembly();
} else if (part == "lid") {
    lid_print();
} else if (part == "preview") {
    box_assembly();
    translate([0, box_width + 10, 0]) lid_print();
    % place_huzzah();
    % color("DarkGrey", 0.15) place_bno();
    % place_battery();
} else if (part == "assembled") {
    % box_assembly();
    % translate([0, 0, box_depth + lid_depth]) mirror([0, 0, 1]) lid();
    place_huzzah();
    color("DarkGrey") place_bno();
    place_battery();
    color("Red")  for (h = huz_holes)
        translate([huz_off_x + h[0], huz_off_y + h[1], box_depth - 0.5])
            cylinder(h = 2, d = 1.5, $fn = 16);
    color("Blue") for (h = bno_holes)
        translate([bno_off_x + h[0], bno_off_y + h[1], box_depth - 0.5])
            cylinder(h = 2, d = 1.5, $fn = 16);
}

echo(str("Box: ", box_length, " × ", box_width, " × ", box_depth, " mm"));
echo(str("Total assembled: ", box_length, " × ", box_width, " × ", box_depth + lid_depth, " mm"));

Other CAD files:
casing/lipo-battery.scad
casing/sandro-box-small.scad
casing/sandro-box.scad
casing/test1.scad
casing/ultimatewaterproofcase_v61.scad
casing/ultimatewaterproofcase_v74.scad

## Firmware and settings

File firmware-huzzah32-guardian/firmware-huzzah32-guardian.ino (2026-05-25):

#include <WiFi.h>
#include <WiFiMulti.h>
#include <WiFiClientSecure.h>
#include <HTTPClient.h>
#include <ArduinoJson.h>
#include <Adafruit_BNO08x.h>
#include <time.h>
#include "config.infomaniak.h"  // swap to config.development.h for local development

#define BATTERY_PIN     A13
#define WIFI_TIMEOUT_MS 15000
#define NTP_TIMEOUT_MS  10000
#define HTTP_TIMEOUT_MS 5000
#define MAX_BUFFER      200   // max buffered readings in RTC (~6400 bytes)

enum HorseState { Standing, LyingDown, Moving, Rolling, Alert, Emergency };

// ── Buffered reading stored in RTC ────────────────────────────────────────────

struct BufferedReading {
  int32_t  unixTime;
  float    pitch;
  float    roll;
  float    acceleration;
  float    angularVelocity;
  int16_t  stillCycles;
  uint8_t  state;
  uint8_t  alertReasonIdx;   // 0=none, 1=BaselineShift, 2=SuddenFall, 3=ActivityCollapse, 4=ColicRolling
};

// ── RTC memory — survives deep sleep ──────────────────────────────────────────

RTC_DATA_ATTR bool        firstBoot           = true;
RTC_DATA_ATTR HorseState  currentState        = Standing;
RTC_DATA_ATTR int         stillCycles         = 0;   // consecutive cycles with very low accel
RTC_DATA_ATTR int         cycleCount          = 0;
RTC_DATA_ATTR bool        timeSynced          = false;

// Config — stored in RTC so firmware doesn't need to fetch every wake
RTC_DATA_ATTR int   sleepNormalS         = 1;
RTC_DATA_ATTR int   sendEveryN           = 60;
RTC_DATA_ATTR float changeAccel          = 1.5f;
RTC_DATA_ATTR float changePitch          = 25.0f;
RTC_DATA_ATTR float changeRoll           = 25.0f;

// Strategy counters
RTC_DATA_ATTR int   rollingCount         = 0;
RTC_DATA_ATTR int   rollingWindowCycles  = 0;
RTC_DATA_ATTR int   activeCycles         = 0;
RTC_DATA_ATTR int   postActiveCycles     = 0;
RTC_DATA_ATTR float emaAccel             = 0;
RTC_DATA_ATTR float emaPitch             = 0;
RTC_DATA_ATTR float emaRoll              = 0;
RTC_DATA_ATTR int   settledCycles        = 0;

// Buffer
RTC_DATA_ATTR int             bufferCount  = 0;
RTC_DATA_ATTR BufferedReading buffer[MAX_BUFFER];

// Detection thresholds — purely dynamics-based, no calibration needed
#define ACCEL_ROLLING      1.5f   // vigorous movement
#define ACCEL_MOVING       0.3f   // any movement
#define ACCEL_STILL        0.2f   // stationary
#define GYRO_ROLLING       0.3f   // rotating
#define ROLLING_ALERT_N    8
#define ROLLING_WINDOW_N   40
#define ACTIVE_MIN_CYCLES  6
#define SUDDEN_STOP_N      6
#define EMA_ALPHA          0.2f
#define EMA_SETTLE_N       5
// CHANGE_ACCEL / CHANGE_PITCH / CHANGE_ROLL are in RTC (fetched from server config)

// ── Runtime (reset each wake) ──────────────────────────────────────────────────

WiFiMulti wifiMulti;
Adafruit_BNO08x bno;

float curQw = 1, curQx = 0, curQy = 0, curQz = 0;
float pitch = 0, roll = 0, acceleration = 0, angularVelocity = 0, temperature = 0;
float batteryVoltage = 0;
const char* alertReason = nullptr;

// ── Setup — runs once per wake cycle ──────────────────────────────────────────

void setup() {
  Serial.begin(115200);
  pinMode(LED_BUILTIN, OUTPUT);

  batteryVoltage = readBatteryVoltage();
  initBno();

  if (firstBoot) {
    connectWifi();
    syncTime();
    fetchConfig();
    readSensor();
    currentState = detectState();
    sendReading(currentState);
    sendDeviceStatus();
    disconnectWifi();
    firstBoot = false;
    Serial.printf("Sleeping %ds (first boot done)\n", sleepNormalS);
    esp_sleep_enable_timer_wakeup((uint64_t)sleepNormalS * 1000000ULL);
    esp_deep_sleep_start();
  }

  readSensor();

  HorseState newState = detectState();
  bool stateChanged   = newState != currentState;
  cycleCount++;

  // Track consecutive still cycles (useful for spotting prolonged immobility)
  if (acceleration < ACCEL_STILL)
    stillCycles++;
  else
    stillCycles = 0;

  Serial.printf("pitch:%6.1f  roll:%6.1f  accel:%.2f  gyro:%.2f  still:%d  state:%s%s\n",
    pitch, roll, acceleration, angularVelocity, stillCycles, stateToString(newState),
    alertReason ? (String(" [") + alertReason + "]").c_str() : "");

  bool isUrgent = (newState == Alert || newState == Emergency);

  if (isUrgent) {
    // Send alert solo so ntfy fires on the backend, flush buffered history first
    currentState = newState;
    connectWifi();
    if (!timeSynced) syncTime();
    flushBuffer();
    sendReading(newState);
    sendDeviceStatus();
    fetchConfig();
    disconnectWifi();
  } else {
    pushToBuffer(newState);
    bool sendDue = (sendEveryN > 0 && cycleCount % sendEveryN == 0) || (bufferCount >= MAX_BUFFER);
    if (sendDue || stateChanged) {
      currentState = newState;
      connectWifi();
      if (!timeSynced) syncTime();
      flushBuffer();
      sendDeviceStatus();
      fetchConfig();
      disconnectWifi();
    } else {
      currentState = newState;
    }
  }

  int sleepSeconds = sleepNormalS;
  if (newState == Alert)     sleepSeconds = max(5, sleepNormalS / 2);
  if (newState == Emergency) sleepSeconds = max(5, sleepNormalS / 3);

  Serial.printf("Sleeping %ds  buffer: %d/%d  cycle: %d (send every %d)\n",
    sleepSeconds, bufferCount, MAX_BUFFER, cycleCount % max(1, sendEveryN), sendEveryN);
  esp_sleep_enable_timer_wakeup((uint64_t)sleepSeconds * 1000000ULL);
  esp_deep_sleep_start();
}

void loop() {}  // never reached — deep sleep restarts setup()

// ── WiFi ──────────────────────────────────────────────────────────────────────

bool ensureWifi() {
  if (WiFi.getMode() == WIFI_OFF) WiFi.mode(WIFI_STA);
  if (wifiMulti.run() == WL_CONNECTED) return true;

  Serial.print("Connecting WiFi");
  unsigned long start = millis();
  while (millis() - start < WIFI_TIMEOUT_MS) {
    if (wifiMulti.run() == WL_CONNECTED) {
      Serial.println(" connected to " + WiFi.SSID());
      return true;
    }
    delay(500);
    Serial.print(".");
  }
  Serial.println(" failed");
  return false;
}

void disconnectWifi() {
  WiFi.disconnect(true);
  WiFi.mode(WIFI_OFF);
}

void connectWifi() {
  struct { const char* ssid; const char* password; } networks[] = WIFI_NETWORKS;
  for (auto& n : networks) wifiMulti.addAP(n.ssid, n.password);
  ensureWifi();
}

// ── Time ──────────────────────────────────────────────────────────────────────

void syncTime() {
  if (!ensureWifi()) return;
  configTime(TZ_OFFSET, 0, NTP_SERVER);
  Serial.print("Syncing time");
  unsigned long start = millis();
  time_t now = 0;
  while (millis() - start < NTP_TIMEOUT_MS) {
    time(&now);
    if (now > 100000) { timeSynced = true; Serial.println(" done"); return; }
    delay(500); Serial.print(".");
  }
  Serial.println(" failed");
}

// ── BNO085 ────────────────────────────────────────────────────────────────────

void initBno() {
  if (!bno.begin_I2C()) {
    Serial.println("BNO085 not found — check wiring");
    while (1) delay(100);
  }
  bno.enableReport(SH2_ROTATION_VECTOR);
  bno.enableReport(SH2_LINEAR_ACCELERATION);
  bno.enableReport(SH2_GYROSCOPE_CALIBRATED);
  delay(100);
}

void readSensor() {
  sh2_SensorValue_t event;
  bool gotRotation = false, gotAccel = false;
  unsigned long start = millis();
  while (millis() - start < 3000 && (!gotRotation || !gotAccel)) {
    if (bno.getSensorEvent(&event)) {
      if (event.sensorId == SH2_ROTATION_VECTOR) {
        curQw = event.un.rotationVector.real;
        curQx = event.un.rotationVector.i;
        curQy = event.un.rotationVector.j;
        curQz = event.un.rotationVector.k;
        pitch = atan2(2*(curQw*curQx + curQy*curQz), 1 - 2*(curQx*curQx + curQy*curQy)) * 180.0f / PI;
        roll  = asin(constrain(2*(curQw*curQy - curQz*curQx), -1.0f, 1.0f)) * 180.0f / PI;
        gotRotation = true;
      }
      if (event.sensorId == SH2_LINEAR_ACCELERATION) {
        acceleration = sqrt(
          pow(event.un.linearAcceleration.x, 2) +
          pow(event.un.linearAcceleration.y, 2) +
          pow(event.un.linearAcceleration.z, 2)
        );
        gotAccel = true;
      }
      if (event.sensorId == SH2_GYROSCOPE_CALIBRATED) {
        angularVelocity = sqrt(
          pow(event.un.gyroscope.x, 2) +
          pow(event.un.gyroscope.y, 2) +
          pow(event.un.gyroscope.z, 2)
        );
      }
    } else {
      delay(5);
    }
  }
  if (!gotRotation) {
    Serial.println("BNO085 timed out — restarting");
    ESP.restart();
  }
}

// ── State detection ───────────────────────────────────────────────────────────

HorseState detectState() {
  bool rolling    = acceleration > ACCEL_ROLLING && angularVelocity > GYRO_ROLLING;
  bool moving     = acceleration > ACCEL_MOVING;
  bool stationary = acceleration < ACCEL_STILL;
  alertReason = nullptr;

  // [5 — least aggressive] ColicRolling: repeated rolling in short window
  rollingWindowCycles++;
  if (rollingWindowCycles > ROLLING_WINDOW_N) {
    rollingWindowCycles = 1;
    rollingCount = 0;
  }

  if (rolling) {
    postActiveCycles = 0;
    rollingCount++;
    activeCycles++;
    if (rollingCount >= ROLLING_ALERT_N) {
      alertReason = "ColicRolling";
      rollingCount = 0;
      return Alert;
    }
    return Rolling;
  }

  // [3] ActivityCollapse: was energetically moving, then abruptly stopped
  if (acceleration > ACCEL_ROLLING) {
    activeCycles++;
    postActiveCycles = 0;
  } else if (activeCycles >= ACTIVE_MIN_CYCLES) {
    postActiveCycles++;
    if (postActiveCycles >= SUDDEN_STOP_N) {
      activeCycles     = 0;
      postActiveCycles = 0;
      alertReason = "ActivityCollapse";
      return Alert;
    }
  } else {
    activeCycles = max(0, activeCycles - 1);
  }

  // [2] SuddenFall: was rolling, now stationary — instant
  if (stationary && currentState == Rolling) {
    alertReason = "SuddenFall";
    return Alert;
  }

  // [1 — most aggressive] BaselineShift: deviation from EMA of accel + pitch + roll
  if (settledCycles == 0) {
    // Seed EMA with actual values so warmup starts from reality, not 0
    emaAccel = acceleration;
    emaPitch = pitch;
    emaRoll  = roll;
    settledCycles++;
  } else if (settledCycles < EMA_SETTLE_N) {
    emaAccel = EMA_ALPHA * acceleration + (1 - EMA_ALPHA) * emaAccel;
    emaPitch = EMA_ALPHA * pitch        + (1 - EMA_ALPHA) * emaPitch;
    emaRoll  = EMA_ALPHA * roll         + (1 - EMA_ALPHA) * emaRoll;
    settledCycles++;
  } else {
    float da = abs(acceleration - emaAccel);
    float dp = abs(pitch        - emaPitch);
    float dr = abs(roll         - emaRoll);
    emaAccel = EMA_ALPHA * acceleration + (1 - EMA_ALPHA) * emaAccel;
    emaPitch = EMA_ALPHA * pitch        + (1 - EMA_ALPHA) * emaPitch;
    emaRoll  = EMA_ALPHA * roll         + (1 - EMA_ALPHA) * emaRoll;
    if (da > changeAccel || dp > changePitch || dr > changeRoll) {
      alertReason = "BaselineShift";
      return Alert;
    }
  }

  return moving ? Moving : Standing;
}

// ── Battery ───────────────────────────────────────────────────────────────────

float readBatteryVoltage() {
  return analogReadMilliVolts(BATTERY_PIN) * 2.0f / 1000.0f;
}

int voltageToPercent(float v) {
  if (v >= 4.2f) return 100;
  if (v >= 3.9f) return (int)((v - 3.9f) / 0.3f * 40) + 60;
  if (v >= 3.7f) return (int)((v - 3.7f) / 0.2f * 30) + 30;
  if (v >= 3.4f) return (int)((v - 3.4f) / 0.3f * 25) + 5;
  return 0;
}

// ── HTTP ──────────────────────────────────────────────────────────────────────

String isoTimestamp() {
  time_t now; time(&now);
  char buf[25];
  strftime(buf, sizeof(buf), "%Y-%m-%dT%H:%M:%S", gmtime(&now));
  return String(buf);
}

String isoFromUnix(int32_t t) {
  time_t ts = (time_t)t;
  char buf[25];
  strftime(buf, sizeof(buf), "%Y-%m-%dT%H:%M:%S", gmtime(&ts));
  return String(buf);
}

const char* stateToString(HorseState s) {
  switch (s) {
    case Standing:  return "Standing";
    case LyingDown: return "LyingDown";
    case Moving:    return "Moving";
    case Rolling:   return "Rolling";
    case Alert:     return "Alert";
    case Emergency: return "Emergency";
    default:        return "Standing";
  }
}

uint8_t alertReasonToIdx(const char* reason) {
  if (!reason)                                return 0;
  if (strcmp(reason, "BaselineShift")    == 0) return 1;
  if (strcmp(reason, "SuddenFall")       == 0) return 2;
  if (strcmp(reason, "ActivityCollapse") == 0) return 3;
  if (strcmp(reason, "ColicRolling")     == 0) return 4;
  return 0;
}

const char* idxToAlertReason(uint8_t idx) {
  switch (idx) {
    case 1: return "BaselineShift";
    case 2: return "SuddenFall";
    case 3: return "ActivityCollapse";
    case 4: return "ColicRolling";
    default: return nullptr;
  }
}

bool post(String url, String body) {
  if (!ensureWifi()) return false;
  Serial.println("POST " + url);
  HTTPClient http;
  WiFiClientSecure secureClient;
  if (url.startsWith("https")) {
    secureClient.setInsecure();
    http.begin(secureClient, url);
  } else {
    http.begin(url);
  }
  http.setTimeout(HTTP_TIMEOUT_MS);
  http.addHeader("Content-Type", "application/json");
  int code = http.POST(body);
  http.end();
  if (code < 0) { Serial.println("POST failed: " + http.errorToString(code)); return false; }
  Serial.printf("  → %d\n", code);
  return code >= 200 && code < 300;
}

// ── Buffer ────────────────────────────────────────────────────────────────────

void pushToBuffer(HorseState state) {
  if (bufferCount >= MAX_BUFFER) return;
  time_t now; time(&now);
  BufferedReading& r = buffer[bufferCount++];
  r.unixTime        = (int32_t)now;
  r.pitch           = pitch;
  r.roll            = roll;
  r.acceleration    = acceleration;
  r.angularVelocity = angularVelocity;
  r.stillCycles     = (int16_t)stillCycles;
  r.state           = (uint8_t)state;
  r.alertReasonIdx  = alertReasonToIdx(alertReason);
}

void flushBuffer() {
  if (bufferCount == 0) return;
  if (!ensureWifi()) return;

  JsonDocument doc;
  JsonArray arr = doc.to<JsonArray>();
  for (int i = 0; i < bufferCount; i++) {
    const BufferedReading& r = buffer[i];
    JsonObject obj = arr.add<JsonObject>();
    obj["timestamp"]       = isoFromUnix(r.unixTime);
    obj["pitch"]           = r.pitch;
    obj["roll"]            = r.roll;
    obj["acceleration"]    = r.acceleration;
    obj["angularVelocity"] = r.angularVelocity;
    obj["lyingCycles"]     = r.stillCycles;
    obj["state"]           = stateToString((HorseState)r.state);
    obj["activity"]        = r.acceleration > ACCEL_MOVING ? "moving" : "stable";
    const char* reason = idxToAlertReason(r.alertReasonIdx);
    if (reason) obj["alertReason"] = reason;
  }

  String body;
  serializeJson(doc, body);
  String url = String(SERVER_URL) + "/horses/" + HORSE_ID + "/readings/batch";
  if (post(url, body)) {
    Serial.printf("Flushed %d readings\n", bufferCount);
    bufferCount = 0;
  }
}

// ── Config ────────────────────────────────────────────────────────────────────

void fetchConfig() {
  if (!ensureWifi()) return;
  HTTPClient http;
  String url = String(SERVER_URL) + "/horses/" + HORSE_ID + "/config";
  if (url.startsWith("https")) {
    WiFiClientSecure* client = new WiFiClientSecure;
    client->setInsecure();
    http.begin(*client, url);
  } else {
    http.begin(url);
  }
  http.setTimeout(HTTP_TIMEOUT_MS);
  int code = http.GET();
  if (code == 200) {
    JsonDocument doc;
    deserializeJson(doc, http.getString());
    sleepNormalS = doc["sleepSeconds"]  | sleepNormalS;
    sendEveryN   = doc["sendEveryN"]    | sendEveryN;
    changeAccel  = doc["changeAccel"]   | changeAccel;
    changePitch  = doc["changePitch"]   | changePitch;
    changeRoll   = doc["changeRoll"]    | changeRoll;
    Serial.printf("Config: sleep=%ds  sendEveryN=%d  changeAccel=%.2f  changePitch=%.1f  changeRoll=%.1f\n",
      sleepNormalS, sendEveryN, changeAccel, changePitch, changeRoll);
    if (doc["reboot"] | false) {
      post(String(SERVER_URL) + "/horses/" + HORSE_ID + "/config/reboot/clear", "{}");
      Serial.println("Remote reboot triggered");
      delay(500);
      ESP.restart();
    }
  }
  http.end();
}

// ── Sending ───────────────────────────────────────────────────────────────────

void sendReading(HorseState state) {
  JsonDocument doc;
  doc["timestamp"]       = isoTimestamp();
  doc["pitch"]           = pitch;
  doc["roll"]            = roll;
  doc["acceleration"]    = acceleration;
  doc["activity"]        = acceleration > ACCEL_MOVING ? "moving" : "stable";
  doc["state"]           = stateToString(state);
  doc["angularVelocity"] = angularVelocity;
  doc["lyingCycles"]     = stillCycles;
  if (alertReason)       doc["alertReason"] = alertReason;
  String body; serializeJson(doc, body);
  post(String(SERVER_URL) + "/horses/" + HORSE_ID + "/readings", body);
}

void sendDeviceStatus() {
  JsonDocument doc;
  doc["timestamp"]      = isoTimestamp();
  doc["batteryVoltage"] = batteryVoltage;
  doc["batteryPercent"] = voltageToPercent(batteryVoltage);
  String body; serializeJson(doc, body);
  post(String(SERVER_URL) + "/horses/" + HORSE_ID + "/status", body);
}

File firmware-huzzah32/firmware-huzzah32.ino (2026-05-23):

#include <WiFi.h>
#include <WiFiMulti.h>
#include <HTTPClient.h>
#include <ArduinoJson.h>
#include <Adafruit_BNO08x.h>
#include <time.h>
#include "config.h"

#define BATTERY_PIN       A13
#define WIFI_TIMEOUT_MS   15000  // give up connecting after 15s
#define NTP_TIMEOUT_MS    10000  // give up NTP sync after 10s
#define HTTP_TIMEOUT_MS   5000   // HTTP request timeout

enum HorseState { Standing, LyingDown, Moving, Rolling };

WiFiMulti wifiMulti;
Adafruit_BNO08x bno;

// Runtime config — defaults match server-side defaults
float tiltThresholdDegrees = 60.0f;
int   lyingConfirmMs       = 10000;
int   heartbeatMs          = 300000;
int   sampleIntervalMs     = 1000;

// Reference orientation — stored during calibration
float       refQw = 1.0f, refQx = 0.0f, refQy = 0.0f, refQz = 0.0f;
float       curQw = 1.0f, curQx = 0.0f, curQy = 0.0f, curQz = 0.0f;
const char* calibrationResult = "unknown";

bool timeSynced = false;

HorseState    currentState = Standing;
bool          isTilted     = false;
unsigned long tiltStart    = 0;
unsigned long lastSend     = 0;
unsigned long lastSample   = 0;

float   lastPitch        = 0;
float   lastRoll         = 0;
float   lastAcceleration = 0;
String  lastActivity     = "stable";

// ── Setup ─────────────────────────────────────────────────────────────────────

void setup() {
  Serial.begin(115200);
  pinMode(LED_BUILTIN, OUTPUT);

  connectWifi();   // non-blocking after timeout
  syncTime();      // skipped if no WiFi
  initBno();       // must be before fetchConfig — fetchConfig may trigger calibrate()
  fetchConfig();   // skipped if no WiFi
  calibrate();
}

// ── WiFi ──────────────────────────────────────────────────────────────────────

bool ensureWifi() {
  if (WiFi.getMode() == WIFI_OFF) WiFi.mode(WIFI_STA);
  if (wifiMulti.run() == WL_CONNECTED) return true;

  Serial.print("Reconnecting WiFi");
  unsigned long start = millis();
  while (millis() - start < WIFI_TIMEOUT_MS) {
    if (wifiMulti.run() == WL_CONNECTED) {
      Serial.println(" connected to " + WiFi.SSID());
      return true;
    }
    delay(500);
    Serial.print(".");
  }
  Serial.println(" failed — continuing offline");
  return false;
}

void disconnectWifi() {
  WiFi.disconnect(true);
  WiFi.mode(WIFI_OFF);
  Serial.println("WiFi off");
}

void connectWifi() {
  struct { const char* ssid; const char* password; } networks[] = WIFI_NETWORKS;
  for (auto& n : networks) wifiMulti.addAP(n.ssid, n.password);
  ensureWifi();
}

// ── Time ──────────────────────────────────────────────────────────────────────

void syncTime() {
  if (!ensureWifi()) return;

  configTime(TZ_OFFSET, 0, NTP_SERVER);
  Serial.print("Syncing time");

  unsigned long start = millis();
  time_t now = 0;
  while (millis() - start < NTP_TIMEOUT_MS) {
    time(&now);
    if (now > 100000) {
      timeSynced = true;
      Serial.println(" done");
      return;
    }
    delay(500);
    Serial.print(".");
  }
  Serial.println(" failed — timestamps will be inaccurate");
}

// ── BNO085 ────────────────────────────────────────────────────────────────────

void initBno() {
  if (!bno.begin_I2C()) {
    Serial.println("BNO085 not found — check wiring");
    while (1) delay(100);  // sensor is required, cannot run without it
  }
  bno.enableReport(SH2_ROTATION_VECTOR);
  bno.enableReport(SH2_LINEAR_ACCELERATION);
  Serial.println("BNO085 ready");
}

void readBno(float &pitch, float &roll, float &acceleration, String &activity) {
  sh2_SensorValue_t event;
  while (bno.getSensorEvent(&event)) {
    if (event.sensorId == SH2_ROTATION_VECTOR) {
      curQw = event.un.rotationVector.real;
      curQx = event.un.rotationVector.i;
      curQy = event.un.rotationVector.j;
      curQz = event.un.rotationVector.k;
      computePitchRoll(event.un.rotationVector, pitch, roll);
    }


    if (event.sensorId == SH2_LINEAR_ACCELERATION) {
      acceleration = sqrt(
        pow(event.un.linearAcceleration.x, 2) +
        pow(event.un.linearAcceleration.y, 2) +
        pow(event.un.linearAcceleration.z, 2)
      );
      activity = acceleration > 0.5f ? "moving" : "stable";
    }
  }
}

void computePitchRoll(sh2_RotationVectorWAcc_t q, float &pitch, float &roll) {
  pitch = atan2(2*(q.real*q.i + q.j*q.k), 1 - 2*(q.i*q.i + q.j*q.j)) * 180.0f / PI;
  roll  = asin (2*(q.real*q.j - q.k*q.i)) * 180.0f / PI;
}

// ── Calibration ───────────────────────────────────────────────────────────────

void calibrate() {
  Serial.println("Calibrating — keep horse still for 10 seconds");

  for (int i = 0; i < 10; i++) {
    digitalWrite(LED_BUILTIN, HIGH);
    delay(500);
    digitalWrite(LED_BUILTIN, LOW);
    delay(500);
  }

  float pitch = 0, roll = 0, acceleration = 0;
  String activity;
  readBno(pitch, roll, acceleration, activity);

  if (acceleration < 0.3f) {
    refQw = curQw; refQx = curQx; refQy = curQy; refQz = curQz;
    Serial.printf("Calibrated — reference stored (pitch: %.1f, roll: %.1f)\n", pitch, roll);
    calibrationResult = "success";
  } else {
    Serial.println("Movement detected during calibration — keeping previous reference");
    calibrationResult = "failed_movement";
  }

  digitalWrite(LED_BUILTIN, HIGH);
}

// ── State detection ───────────────────────────────────────────────────────────

float tiltAngleDeg() {
  float dot = refQw*curQw + refQx*curQx + refQy*curQy + refQz*curQz;
  if (dot < 0) dot = -dot;
  if (dot > 1.0f) dot = 1.0f;
  return 2.0f * acos(dot) * 180.0f / PI;
}

HorseState detectState(float pitch, float roll, float acceleration) {
  bool tilted = tiltAngleDeg() > tiltThresholdDegrees;
  bool moving = acceleration > 0.5f;

  if (tilted && moving) {
    isTilted = false;
    return Rolling;
  }

  if (tilted) {
    if (!isTilted) {
      isTilted  = true;
      tiltStart = millis();
    }
    return millis() - tiltStart >= (unsigned long)lyingConfirmMs ? LyingDown : currentState;
  }

  isTilted = false;
  return moving ? Moving : Standing;
}

// ── Battery ───────────────────────────────────────────────────────────────────

float readBatteryVoltage() {
  return analogReadMilliVolts(BATTERY_PIN) * 2.0f / 1000.0f;
}

int voltageToPercent(float v) {
  if (v >= 4.2f) return 100;
  if (v >= 3.9f) return (int)((v - 3.9f) / 0.3f * 40) + 60;
  if (v >= 3.7f) return (int)((v - 3.7f) / 0.2f * 30) + 30;
  if (v >= 3.4f) return (int)((v - 3.4f) / 0.3f * 25) + 5;
  return 0;
}

// ── HTTP ──────────────────────────────────────────────────────────────────────

String isoTimestamp() {
  time_t now;
  time(&now);
  char buf[25];
  strftime(buf, sizeof(buf), "%Y-%m-%dT%H:%M:%S", gmtime(&now));
  return String(buf);
}

const char* stateToString(HorseState state) {
  switch (state) {
    case Standing:  return "Standing";
    case LyingDown: return "LyingDown";
    case Moving:    return "Moving";
    case Rolling:   return "Rolling";
    default:        return "Standing";
  }
}
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

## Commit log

2026-05-19 Add nav, calibrate-page, SensorReading data.
2026-05-23 Update to read battery more accurately.
2026-05-23 Update Guardian to go away from calibrating and detect from context.
2026-05-25 Fix potential leak in guardian
    [firmware-huzzah32-guardian.ino]
2026-05-25 Add limit for SensorReadings.
2026-05-25 Fix switch in ReadingController.
2026-05-27 Add casing information and stls.
    [3405 Adafruit HUZZAH32 ESP32 Feather.stl, 4754 BNO085 STEMMA QT.stl, casing-sandro.scad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]
2026-05-27 Add lipo-battery.scad.
    [lipo-battery.scad]
2026-05-27 Add stl files.
    [Lid.stl, MainBody.stl, Sample1-UltimateWaterproofCase_V6.stl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]
2026-05-27 Add parametric enclosure for LiPo + Huzzah + BNO085
    - Corner mounting posts using screw_offset (post body merges into wall,
    screw hole stays clear of wall face)
    - BNO085 mounting holes in lid detected from STL (2.50 mm from each edge,
    M2.5 clearance)
    - BNO085 lid position centred in x, pushed toward far edge in y
    - Lid countersunk holes aligned with mounting posts via screw_offset
    [sandro-box.scad]
2026-05-27 Update holes to match bno
    [sandro-box.scad]
2026-05-27 Add reference so electronics does not get printed.
    [sandro-box.scad]
2026-05-27 Add stl file for print.
    [sandro-box.stl]
2026-05-28 Add scad with heat inserts.
    [horse-collar-with-heat-inserts.scad, sandro-box-small.scad]
2026-05-28 Hide ox_body.
    [horse-collar-with-heat-inserts.scad]
2026-05-29 Draw body.
    [horse-collar-with-heat-inserts.scad]
2026-05-29 Add battery_clearance.
    [horse-collar-with-heat-inserts.scad]
2026-05-29 Move pillars into the edge.
    [horse-collar-with-heat-inserts.scad]
2026-05-29 Move positions of component for better wiring.
    [horse-collar-with-heat-inserts.scad]
2026-05-29 Prepare print-build.
    [horse-collar-with-heat-inserts.scad]
2026-05-29 Add lid assembled boolean.
    [horse-collar-with-heat-inserts.scad]
2026-06-02 Head inserts changes.
    [horse-collar-with-heat-inserts-box.stl, horse-collar-with-heat-inserts-lid.stl, horse-collar-with-heat-inserts.scad]
